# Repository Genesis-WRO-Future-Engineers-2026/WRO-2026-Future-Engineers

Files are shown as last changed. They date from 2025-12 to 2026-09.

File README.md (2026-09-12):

# Team Génesis
<p align="center">

    <br>
    <i>Logo del Equipo</i>
</p>

<p align="center">
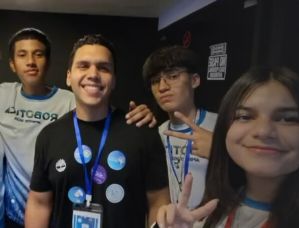
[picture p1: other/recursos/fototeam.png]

    <br>
    <i>Foto del Equipo</i>
</p>

# WRO - Future Engineers - Documentación del proyecto de robótica

## 👥Miembros del equipo
- **Johelis Acosta**
 *Rol*: Electrónica y mecánica
- **Miguel Mejías**
 *Rol*: Programador
- **Guillermo Fernández**
 *Rol*: Programador y diseñador

## 🧑🏻‍🔧Entrenador
- **Oswal Melean**
  *Ingeniero mecánico*

---

Bienvenidos a nuestro repositorio. Somos un grupo estudiantil dedicado a la robótica y la innovación, y en este espacio documentamos nuestro proceso de diseño: arquitectura de hardware, desarrollo de código, selección de componentes y el historial de pruebas de nuestro robot Eva01.

## 🔍Tabla de contenido

<!-- toc -->

- [1. 📚Descripción general](#1-descripción-general)
  - [1.1 Sobre el proyecto](#11-sobre-el-proyecto)
  - [1.2 Imagenes de Eva01](#12-imagenes-de-eva01)
  - [1.3 Video demostrativo](#13-video-demostrativo)
- [2. 🔩Movilidad y diseño mecánico](#2-movilidad-y-diseño-mecánico)
  - [2.1 Sistema de tracción](#21-sistema-de-tracción)
  - [2.2 Dirección](#22-direccion)
  - [2.3 Diseño del chasis](#23-diseño-del-chasis)
-  [3. 🔋Arquitectura de potencia y sensores](#3-arquitectura-de-potencia-y-sensores)
   - [3.1 Fuente de alimentación](#31-fuente-de-alimentación)
   - [3.2 Sensores y cámara](#32-sensores-y-cámara)
   - [3.3 Unidades de procesamiento](#33-unidades-de-procesamiento)
   - [3.4 Diagramas eléctricos](#34-diagramas-eléctricos)
   - [3.5 Consumo de energía](#35-consumo-de-energía)
- [4. 📐Arquitectura de software y estrategia para obstáculos](#4-arquitectura-de-software-y-estrategia-para-sortear-obstáculos)
  - [4.1 Reto abierto](#41-reto-abierto)
  - [4.2 Reto de obstáculos](#42-reto-de-obstáculos)
  - [4.3 Estacionamiento en paralelo](#43-estacionamiento-en-paralelo)
- [5. ⚙Pensamiento sistémico y decisiones de ingeniería](#5-pensamiento-sistémico-y-decisiones-de-ingeniería)
  - [5.1 Lenguajes de programación](#51-lenguajes-de-programación)
  - [5.2 Estructura del código](#52-estructura-del-código)
  - [5.3 Instrucciones de compilación](#53-instrucciones-de-compilación)
- [6. 📝Lista de componentes](#6-lista-de-componentes)
- [7. 💎Archivos de modelos 3D](#7-archivos-de-modelos-3d)
  - [7.1 Archivos STL originales](#71-archivos-stl-originales)
  - [7.2 Archivos modificados Eva01](#72-archivos-modificados-eva01)
- [8. 🛠️Instrucciones de montaje](#8-instrucciones-de-montaje)

    <!-- tocstop -->

## 1. 📚Descripción general

### 1.1 Sobre el proyecto

Este proyecto se centra en el diseño, la construcción y la programación de un vehículo autónomo capaz de superar con precisión y rapidez los retos y obstáculos de la competición «WRO Future Engineers».

Para el equipo Genesis, este reto representa la oportunidad perfecta para poner en práctica la teoría, combinando la pasión por la innovación tecnológica con la resolución creativa de problemas a través de un proceso sistemático de investigación, creación de prototipos e iteración constante.

La estructura de nuestro robot **Eva01** se basa en una arquitectura robusta inspirada en el hardware *zcar* (https://github.com/alexyu132/zcar). Hemos sometido este diseño a un exhaustivo proceso de reingeniería utilizando Fusion 360 y Blender para optimizar las dimensiones de los alojamientos de tornillos y tuercas, así como para personalizar las piezas y lograr un ajuste perfecto de nuestros componentes.

El núcleo del sistema está controlado por una Raspberry Pi 3 B+, que gestiona la lógica principal, con el apoyo de un módulo ESP32 S2 Mini para controlar los sensores y actuadores. Para lograr una navegación precisa y una evitación eficiente de obstáculos, el robot integra sensores de tiempo de vuelo VL53L0X (ToF) junto con un giroscopio MPU-6050 para la estabilización y la orientación de la trayectoria.

Todo este proceso de desarrollo ha estado respaldado por una documentación detallada que no solo optimiza nuestro flujo de trabajo, sino que también demuestra nuestras habilidades técnicas y de colaboración, así como nuestro compromiso con el aprendizaje práctico.

---

### 1.2 Imagenes de Eva01

<table>
  <tr>
    <td align="center">
      <b>Vista frontal</b><br>
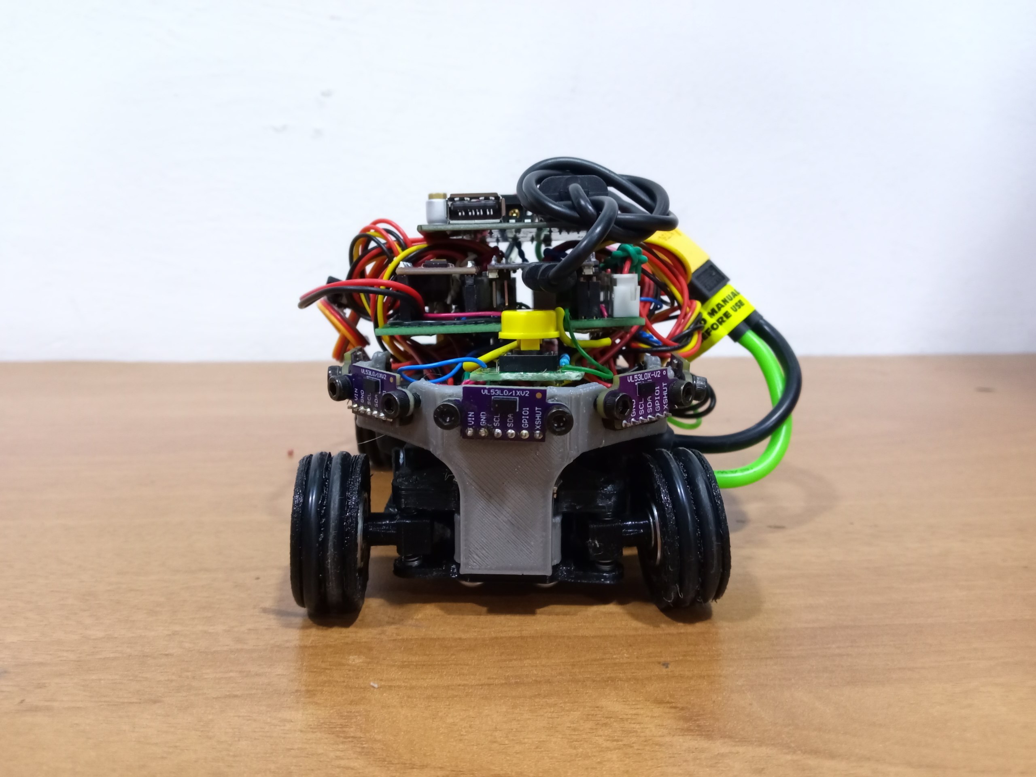
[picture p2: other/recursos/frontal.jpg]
      
    </td>
    <td align="center">
      <b>Vista trasera</b><br>
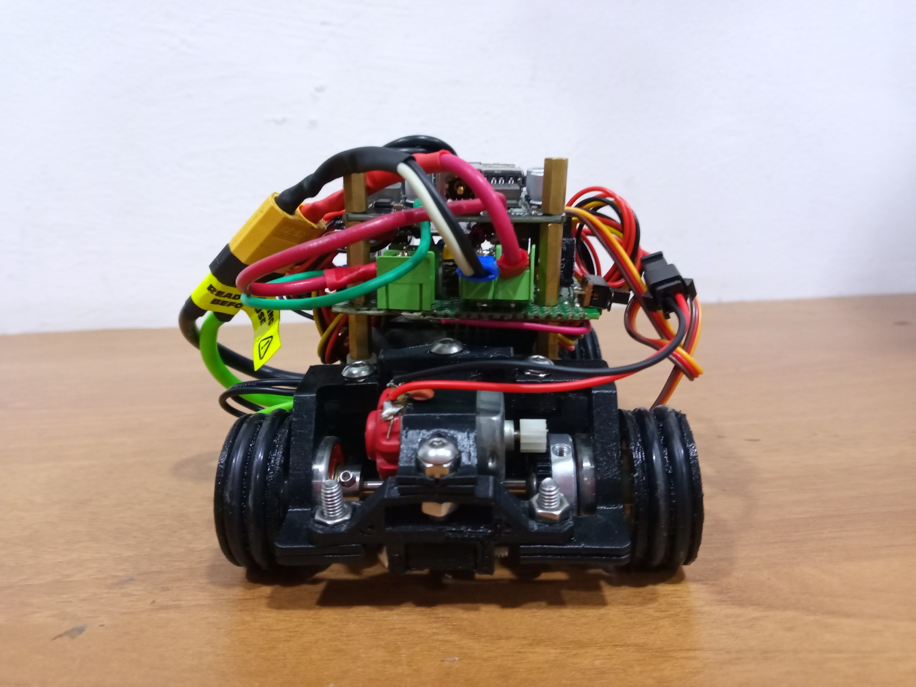
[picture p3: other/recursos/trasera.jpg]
      
    </td>
    <td align="center">
      <b>Vista lateral izquierda</b><br>
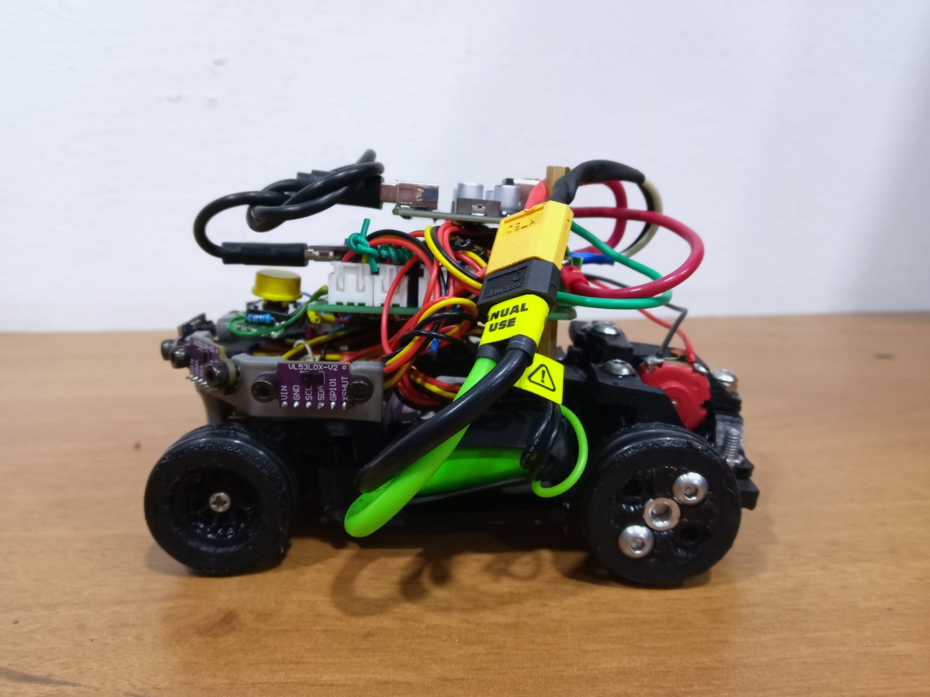
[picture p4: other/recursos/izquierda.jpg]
      
    </td>
  </tr>
  <tr>
    <td align="center">
      <b>Vista lateral derecha</b><br>
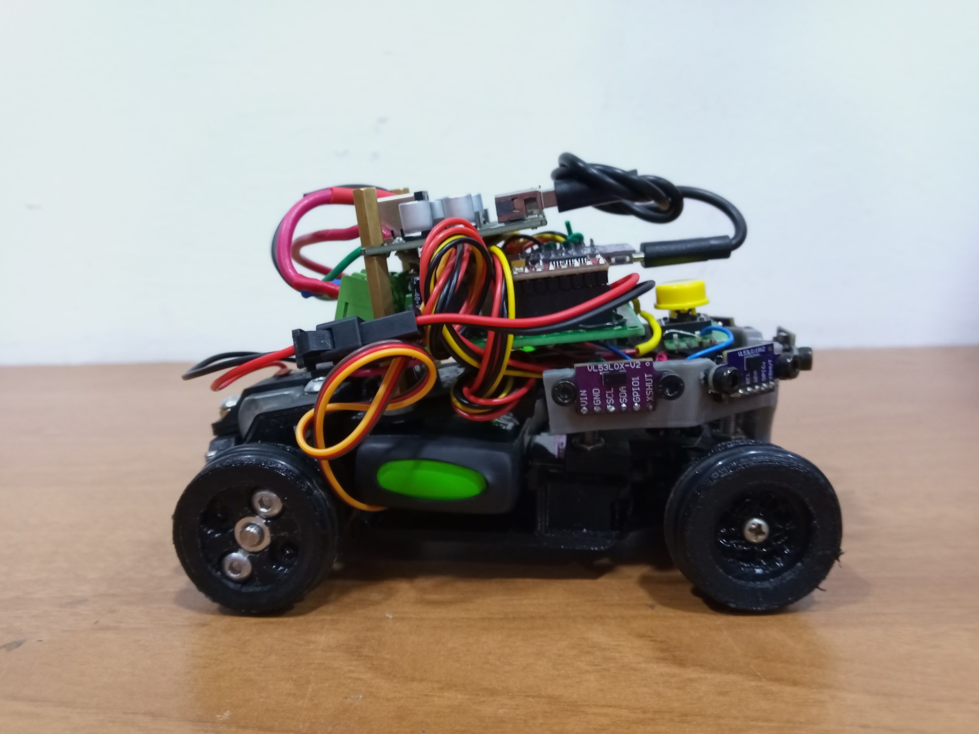
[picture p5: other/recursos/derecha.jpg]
      
    </td>
  <td align="center">
  <b>Vista desde arriba</b><br>
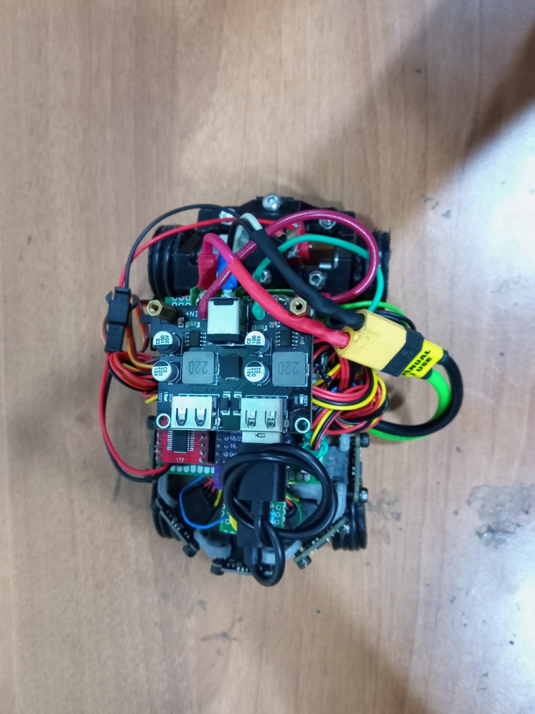
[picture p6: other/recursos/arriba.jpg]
  
</td>
    <td align="center">
      <b>Vista desde abajo</b><br>
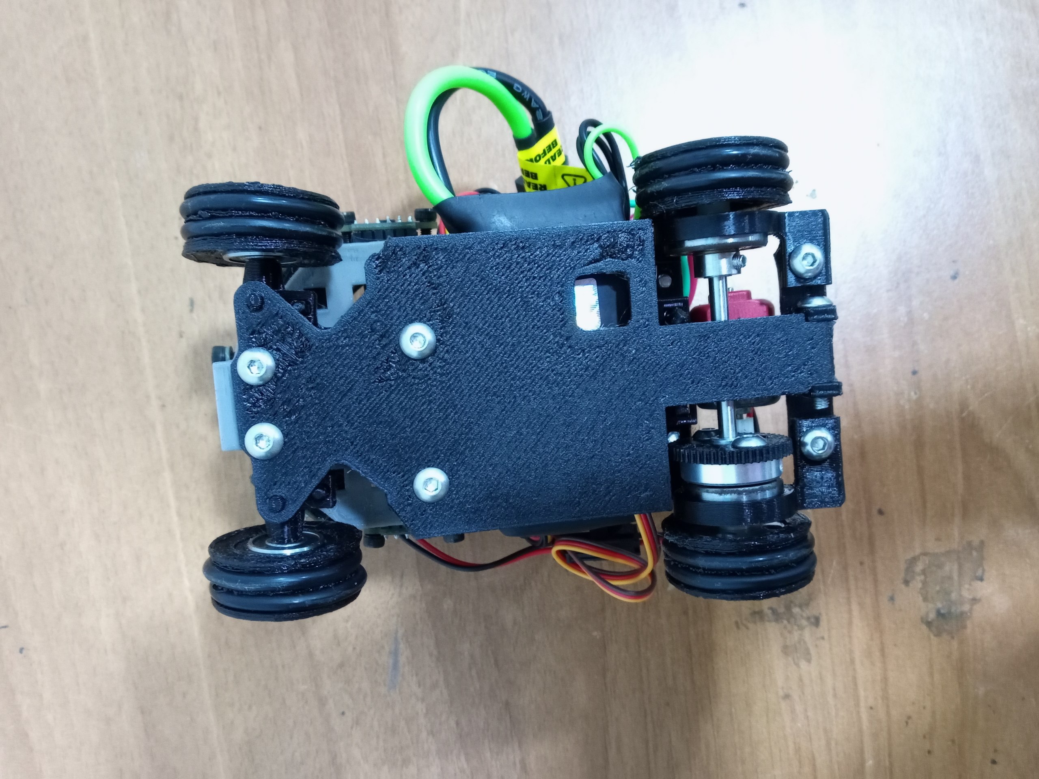
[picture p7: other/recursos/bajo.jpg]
      
    </td>
  </tr>
</table>

---

### 1.3 Video demostrativo

Parte 1: Vídeo del reto sin obstáculos (https://youtu.be/Bd5FpVkRgWs)

[Parte 2: Vídeo del reto de obstáculos]()

<p align="right">
  <a href="#top">Back To Top</a>
</p>

---

## 2. 🔩Movilidad y diseño mecánico

- **Sistema de tracción:** tracción diferencial en 2 ruedas (ruedas traseras).
- **Dirección:** dirección en las ruedas delanteras mediante el servomotor MG90S.

### 2.1 Sistema de tracción

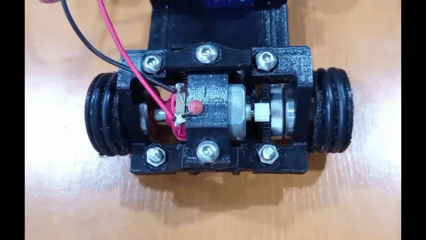
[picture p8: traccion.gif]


**Motor: Micro motor dc 130**

<table>
  <tr>
    <td align="center" width="300" >
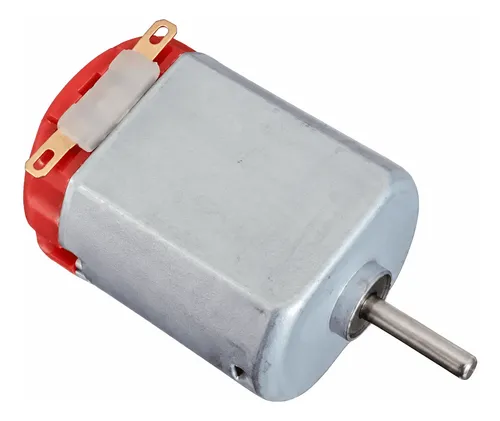
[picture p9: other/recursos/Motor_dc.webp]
   
    </td>
    <td>
      <h3>Especificaciones:</h3>
      <ul>
          <li><b>Voltaje:3 V – 6 V</li>
          <li><b>Velocidad sin carga:12500 – 15000 RPM (a 6V)</li>
          <li><b>Stall torque:0,15 – 0,20 kg-cm</li>
          <li><b>Corriente sin carga:0,07 A – 0,15 A</li>
          <li><b>Relación de transmisión:1:1 (sin reductora)</li>
      </ul>
    </td>
  </tr>
</table>

**Motivo de la selección:**

- **Diseño compacto y liviano:** Permite optimizar al máximo el peso del chasis, manteniendo el centro de gravedad bajo y reduciendo la demanda sobre la batería durante las rondas de competencia.

- **Respuesta y aceleración rápida:** Presenta una baja inercia mecánica, facilitando aceleraciones inmediatas y cambios de velocidad.

- **Fácil integración:** Es una alternativa sumamente accesible, fácil de montar y rápida de reemplazar si se requiere mantenimiento durante las pruebas.

**Sistema de Tracción y Trabajo Futuro:**

El motor acciona las ruedas traseras a través de un eje metálico continuo de transmisión directa. Esta configuración garantiza que ambas ruedas reciban el mismo par y mantengan una velocidad sincronizada al 100%, eliminando descompensaciones en el avance en línea recta y evitando pérdidas por fricción de mecanismos complejos.

Aunque el eje rígido requiere compensar el radio de giro a través de la dirección delantera con el servomotor MG90S, la navegación actual depende completamente del control por sensores externos (VL53L0X y MPU6050). Si bien esta solución es económica y funcional para la etapa actual del prototipo, la falta de retroalimentación interna limita la precisión en el control de la distancia recorrida. Por ello, nuestra visión a futuro es reemplazar este por un motor con encoder integrado, lo que simplificará la programación y nos permitirá implementar un control mucho más preciso en pista.

**Montaje:**

Se instala mediante una abrazadera de motor impresa en 3D atornilladas al chasis. Esto permitirá futuras modificaciones para el mejoramiento de la tracción. 

[Abrazadera del motor](<models/Stls/Soporte motor.stl>)

- Cables del motor conectados directamente al puente h TB6612FNG.
- Ruedas conectadas a su tren de rodaje impreso en 3D con filamento PETG.

---

### 2.2 Dirección

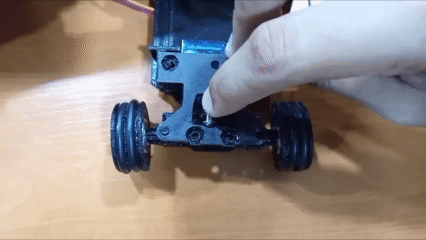
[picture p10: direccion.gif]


#### Servomotor: MG90S

<table>
  <tr>
    <td align="center" width="300" >
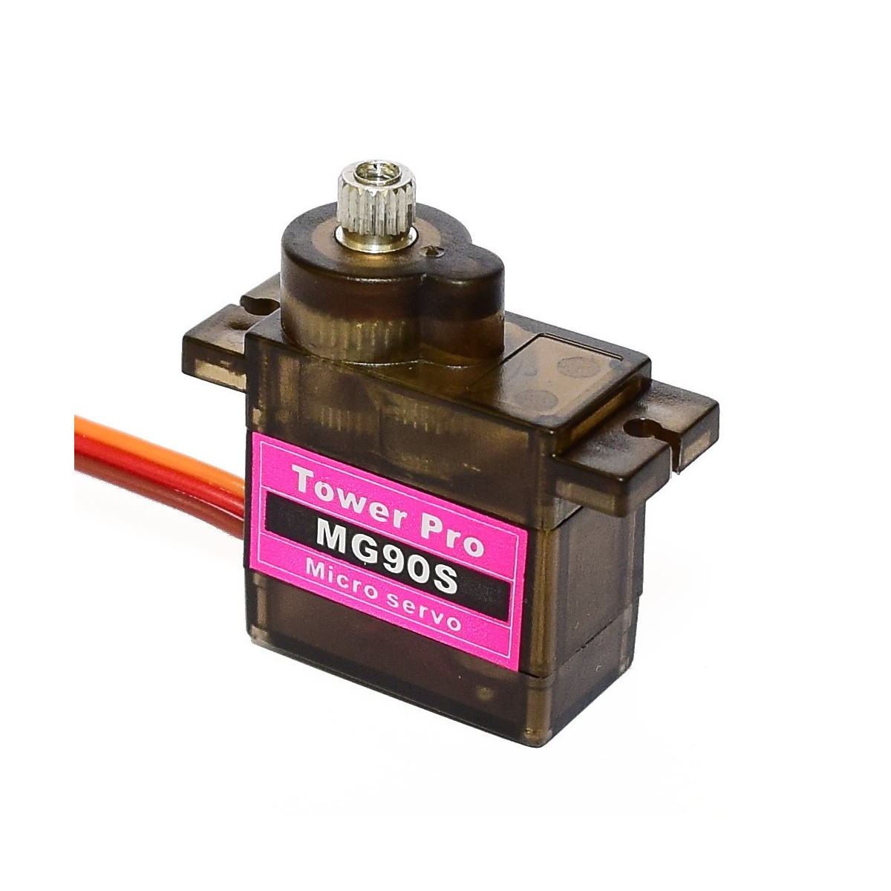
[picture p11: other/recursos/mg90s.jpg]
   
    </td>
    <td>
      <h3>Especificaciones:</h3>
      <ul>
          <li><b>Voltaje:4,8 V – 6,0 V</li>
          <li><b>Velocidad:0,08 – 0,10 s/60°</li>
          <li><b>Stall torque:1,8 – 2,2 kgf/cm</li>
          <li><b>Engranaje:Metal</li>
          <li><b>Tipo:Análogo / Digital</li>
      </ul>
    </td>
  </tr>
</table>

#### Motivo de la selección:

- Su pequeño tamaño y la interfaz PWM facilitan su control a través del ESP32-S2 Mini.

- Tiene el par de bloqueo (stall torque) suficiente para dirigir las ruedas delanteras con precisión.

- Ofrece un equilibrio entre velocidad y estabilidad durante los giros y los cambios de dirección.

- Este servomotor se utiliza ampliamente en la robótica, por lo que existe mucha documentación y kits de montaje disponibles.

Tomando como base el diseño modificado del hardware "zcar", adaptamos su dirección Ackermann para optimizar el paso por curva. Este sistema evita que los neumáticos deslicen al hacer que la rueda interior de la curva gire con un ángulo más pronunciado que la exterior.

El mecanismo funciona mediante un servomotor que desplaza un pin central a través de una ranura, empujando los brazos articulados de las ruedas. La clave radica en la inclinación del pin respecto a la barra de empuje: al mover el servo, se aplica una mayor diferencia angular a la rueda interna del giro. Así se logra un paso por curva fluido y preciso.

 *Imagen creada a partir de referencias de la web*
 
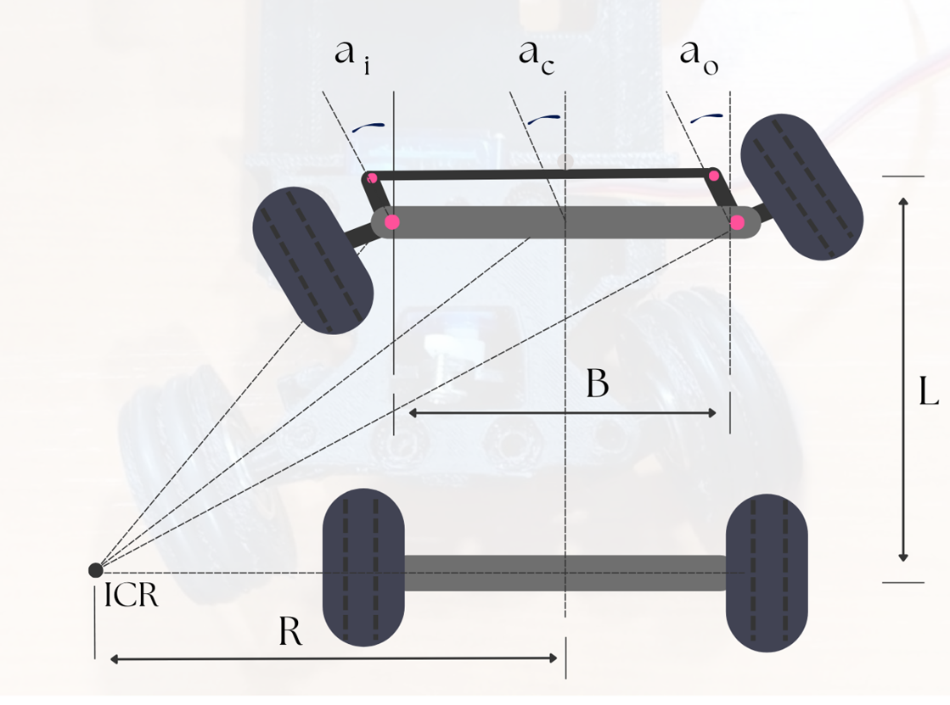
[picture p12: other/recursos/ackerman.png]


Describiremos a continuación el significado de cada término:

**ICR (Centro Instantáneo de Rotación):** Es el punto alrededor del cual el eje delantero está girando.

**R :** Es la radio del giro del vehículo, medida desde el ICR hasta el centro del eje trasero.

**L :** Es la distancia entre el eje delantero y el eje trasero de Eva01, o la distancia de nuestro eje transmisor.

**B :** Es la distancia entre los muñones de dirección (La pieza en la que va la rueda y se conecta a la dirección).

**a(i) :** Es el ángulo de giro de nuestra rueda interior respecto a la curva.

**a(o) :** Es el ángulo de nuestra rueda exterior respecto al giro.

Rediseñamos y mejoramos el mecanismo de dirección para satisfacer las demandas físicas y mecánicas del robot. Los aspectos clave de este desarrollo fueron:

- **Modelado en Autodesk Fusion 360:** Partimos del diseño base y utilizamos Fusion 360 para realizar las modificaciones geométricas necesarias en el sistema de dirección, adaptando componentes clave como la barra de la dirección y las dimensiones del muñón que sostiene las ruedas.

- **Prototipado rápido e iteración física:** Basamos nuestras pruebas en la fabricación directa de componentes. Imprimíamos en 3D las piezas modificadas en formato STL y evaluamos su desempeño en el chasis real; si un elemento no funcionaba según lo previsto (como requerir un mayor largo en la barra de dirección), ajustábamos el modelo 3D y volvíamos a imprimir.

- **Adaptación de rines y ruedas (Dirección vs. Tracción):** Para integrar de forma adecuada el eje metálico en el sistema de tracción trasera, adaptamos la geometría de los rines. Los rines delanteros (dirección) se diseñaron ligeramente más pequeños en diámetro interno, lo que hace que el perfil del neumático sea más grueso en esa zona; sin embargo, físicamente las ruedas delanteras y traseras mantienen exactamente el mismo tamaño externo para conservar el equilibrio y la altura del chasis.

- **Fabricación en PETG:** Todas las piezas adaptadas e impresas fueron fabricadas utilizando filamento PETG (a excepción de los neumáticos impresas en TPU), garantizando mayor resistencia mecánica, tenacidad ante impactos y durabilidad en las uniones y puntos de estrés térmico o mecánico.

#### Calibración e implementación

Para asegurarnos de que la dirección funcionara correctamente en ambas direcciones, llevamos a cabo un proceso de calibración práctico e iterativo:

- **Ajuste dimensional:** Modificamos de forma iterativa el modelo digital (ajustando la barra de dirección y el muñón) y probamos el encaje físico de las piezas impresas.

- **Verificación mecánica:** Tras cada impresión y montaje, evaluamos el comportamiento dinámico del servo y el varillaje, comprobando que las ruedas giraran de forma simétrica, sin fricción excesiva ni holguras en el muñón.

- **Consolidación del diseño:** Una vez alcanzado el ángulo de giro óptimo, fijamos las dimensiones definitivas en el modelo final.

#### Montaje:

Todo el mecanismo de dirección mejorado se ensambló de manera robusta utilizando un sistema de uniones impresas con filamento con tornillos y tuercas M3, sujetando firmemente el servo, los muñones y las barras de dirección a la estructura principal del chasis.

### 2.3 Diseño del chasis

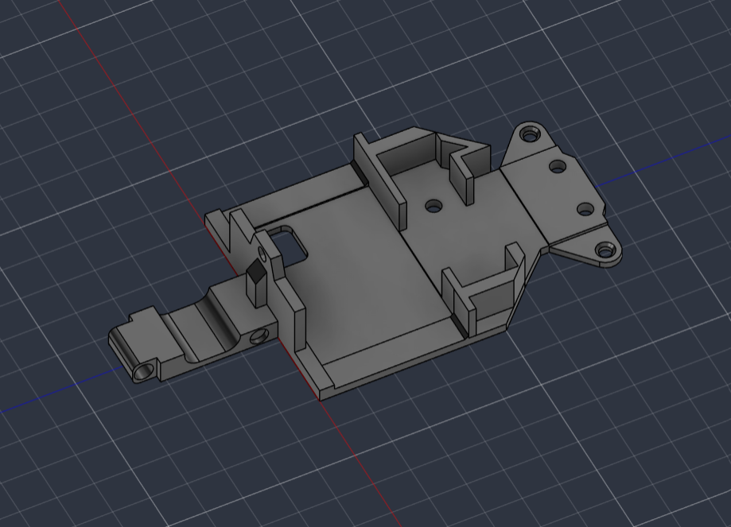
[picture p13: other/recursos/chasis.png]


|**Dimensiones**|**Valor**|
|---|---|
| Largo | 126 mm  |
| Ancho | 62 mm |
| Alto máx | 25.3 mm |
| Alto min | 2.5 mm  |

#### Diseño y Estructura del Chasis

El chasis principal de nuestro vehículo toma como base un diseño de código abierto, el cual fue adaptado y optimizado mediante Autodesk Fusion 360 para ajustarse a nuestro sistema de tracción y geometría de dirección. Para garantizar la modularidad y facilitar el mantenimiento, la transmisión trasera y el mecanismo de dirección delantero con su servomotor se montan en placas desmontables impresas en 3D. Estas placas permitieron realizar ajustes finos durante la fase de pruebas hasta alcanzar una alineación precisa con el resto del tren motriz.

La distribución interna coloca los componentes de mayor peso en los extremos (motor y servo), reservando la zona central para la electrónica. Allí, una placa de circuito a medida simplifica el cableado y optimiza el espacio. El diseño se complementa con piezas independientes imprimibles, como abrazaderas para el motor y soportes dedicados para los sensores, lo que facilita el reemplazo o ajuste individual de cada elemento.

Todo el conjunto estructural fue impreso en filamento PETG, seleccionado por su mayor resistencia mecánica, durabilidad frente a impactos y tolerancia térmica en comparación con el PLA convencional.

<p align="right">
  <a href="#top">Back To Top</a>
</p>

---

## 3. 🔋Arquitectura de potencia y sensores

### 3.1 Fuente de alimentación

#### Batería high performance

<table>
  <tr>
    <td align="center" width="300" >
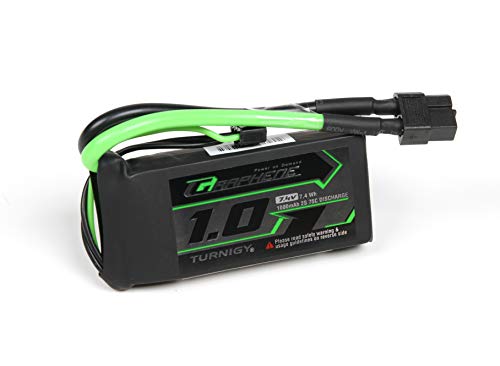
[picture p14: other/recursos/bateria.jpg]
   
    </td>
    <td>
      <h3>Específicacones:</h3>
      <ul>
          <li>Modelo: Turnigy Graphene Panther</li>
          <li>Voltaje nominal: 7.4 V 2S</li>
          <li>Voltaje Máximo: 8.4 V (4.2 V por celda)</li>
          <li>Voltaje de Corte Seguro: 6.4 V - 6.6 V (3.2 V - 3.3 V por celda)</li>
          <li>Capacidad: 1000 mAh (1.0 Ah)</li>
          <li>Tasa de Descarga: 75C constante</li>
          <li>Tiempo de carga: 1.25 Horas</li>
      </ul>
    </td>
  </tr>
</table>

Para el Eva 01, diseñamos un sistema de distribución de energía centralizado a partir de una única batería, priorizando la estabilidad de la lógica de control frente al consumo de los motores.

Seleccionamos esta batería principalmente por su alta capacidad de entrega de corriente constante. Al trabajar con motores con tracción y un servomotor de dirección que se activan de forma simultánea, el sistema demanda picos de corriente muy elevados. La tecnología de esta batería nos garantiza que el flujo de energía sea masivo y constante, evitando caídas de tensión bruscas que podrían reiniciar o desestabilizar la Raspberry Pi 3 b+ o la ESP32-S2. Además, su excelente relación peso-potencia nos permite mantener el chasis ligero sin sacrificar la autonomía.

Para evitar que el ruido inductivo de los motores interfiriera con los procesadores, decidimos dividir la alimentación en tres ramificaciones independientes:

```text
                  ┌──► [Conversor Step-Down USB 5V] ──────► Raspberry Pi 3 B+ (Procesamiento)
                  │
[Batería LiPo 2S]─┼──► [Regulador Lineal LM7805] ────────► Servomotor (Dirección)
                  │
                  ├──► [Puente H TB6612FNG (Paralelo)] ──► Motor DC 6V (Tracción)
                  │         └─► [ESP32-S2] (Lógica)
                  │
                  └──► [Divisor de Tensión] ────────────► Pin 14 ESP32-S2 (Monitoreo)
```

- **Alimentación de la Raspberry Pi 3 B+**
Utiliza un **conversor regulador (Step-Down) doble USB** conectado directo a la batería, garantizando el suministro estable de 5V y el amperaje continuo que requiere la Pi para procesar datos sin caídas de voltaje.

- **Incremento de Torque (Puente H en Paralelo)**
Para maximizar la fuerza del motor de tracción de 6V, **conectamos en paralelo ambos canales del puente H TB6612FNG** (puenteando señales de control y salidas de potencia). Esto duplica la capacidad de corriente, evitando sobrecalentamientos ante altas exigencias mecánicas. La ESP32-S2 toma su alimentación lógica de esta etapa.

- **Aislamiento del Servomotor de Dirección**
Alimentamos el servomotor de forma exclusiva con un regulador lineal **LM7805** para aislar por completo el ruido que generan sus movimientos rápidos, protegiendo la estabilidad de los microcontroladores.

- **Monitoreo y Protección de la Batería**
Implementamos un **divisor de tensión** conectado a un pin 14 de la ESP32-S2 para medir el voltaje de la batería de forma segura. Si el nivel de carga desciende de su límite crítico, el sistema activa un **LED de advertencia** para evitar la degradación de las celdas.

#### Conversor regulador (Step-Down) doble USB

<table>
  <tr>
    <td align="center" width="300" >
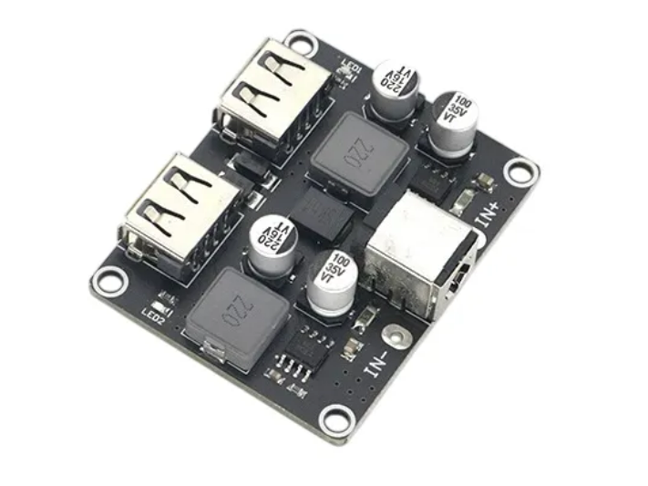
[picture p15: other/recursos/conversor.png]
   
    </td>
    <td>
      <h3>Especificaciones:</h3>
      <ul>
          <li><b>Rango de voltaje de entrada:6 V – 32 V DC</li>
          <li><b>Voltaje de salida:5 V por defecto (3 V – 12 V en carga rápida)</li>
          <li><b>Potencia de salida máxima:24 W por puerto (ej. 5V/3.4A, 9V/2.5A, 12V/2A)</li>
          <li><b>Eficiencia de conversión:90% – 97%</li>
      </ul>
    </td>
  </tr>
</table>

#### Controlador del motor: TB6612FNG

<table>
  <tr>
    <td align="center" width="300" >
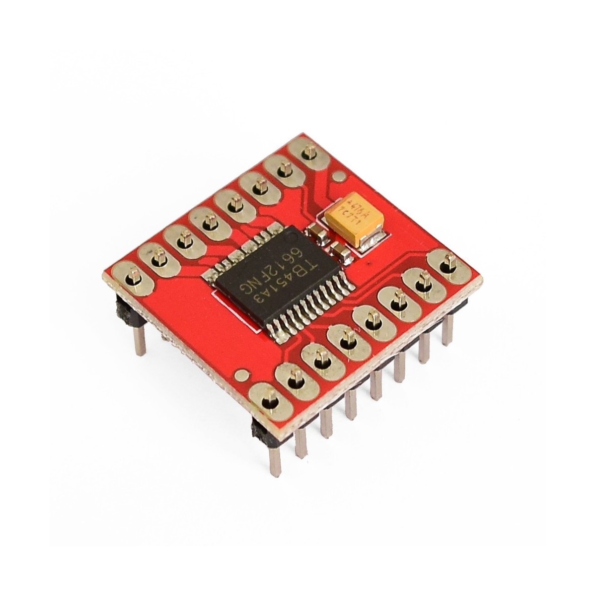
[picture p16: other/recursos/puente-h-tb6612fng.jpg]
   
    </td>
    <td>
      <h3>Especificaciones:</h3>
      <ul>
          <li><b>Rango de voltaje de motores (VM): 4.5 V – 13.5 V</li>
          <li><b>Voltaje de lógica (VCC): 2.7 V – 5.5 V</li>
          <li><b>Corriente de salida continua: 1.2 A por canal (2.4 A en paralelo)</li>
          <li><b>Corriente pico máxima: 3.2 A por canal</li>
          <li><b>Resistencia típica R<sub>DS(on)</sub> (alta + baja):</b> 0.5 Ω</li>
          <li><b>Frecuencia máxima de PWM: Hasta 100 kHz</li>
      </ul>
    </td>
  </tr>
</table>

#### Regulador lineal: LM7805

<table>
  <tr>
    <td align="center" width="300" >
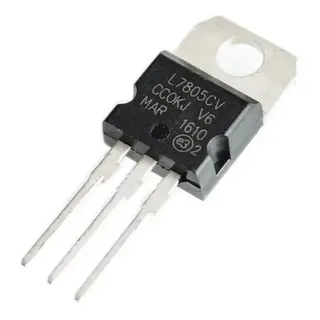
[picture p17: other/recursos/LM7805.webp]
   
    </td>
    <td>
      <h3>Especificaciones:</h3>
      <ul>
          <li><b>Voltaje de salida:5 V DC (fijo)</li>
          <li><b>Rango de voltaje de entrada:7 V – 25 V</li>
          <li><b>Corriente de salida máxima:1.5 A</li>
      </ul>
    </td>
  </tr>
</table>

---

### 3.2 Sensores y cámara

#### Sensor tiempo de vuelo VL53L0X

El VL53L0X es un sensor de distancia pequeño y muy utilizado que emplea la tecnología de tiempo de vuelo (ToF) para medir la distancia a un objeto mediante la emisión de un pulso de luz láser infrarroja invisible y el cálculo del tiempo que tarda en regresar.

Lo hemos elegido para este proyecto debido a tres ventajas clave:

-  **Tamaño ultracompacto**: su reducido tamaño permite integrarlo fácilmente en espacios reducidos sin comprometer el diseño del prototipo.
  
-  **Fácil integración**: ofrece una excelente compatibilidad y bibliotecas listas para usar, lo que simplifica enormemente la programación.
  
-  **Alta velocidad**: es capaz de realizar mediciones de distancia por láser en un tiempo récord, lo que garantiza lecturas rápidas, precisas y en tiempo real.

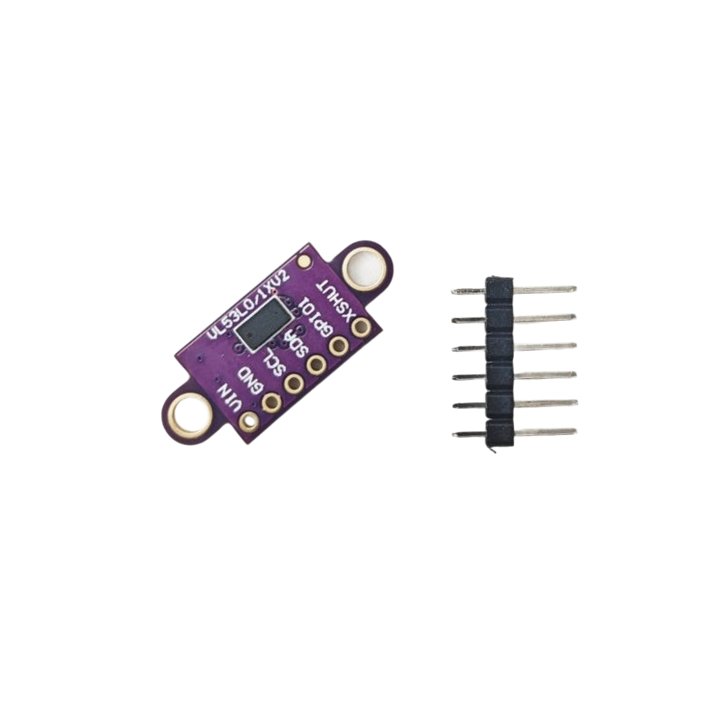
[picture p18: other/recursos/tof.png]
  

|**Dimensiones**|**Valor**|
|---|---|
| Largo | 25 mm |
| Alto | 1 mm |
| Ancho | 10,7 mm |
| Peso | 0,8 g |

 **Observaciones**

 Al trabajar con la tecnología Time-of-Flight (ToF) mediante un láser VCSEL infrarrojo invisible, el sensor emite un haz de luz y necesita que los fotones reboten en la superficie y regresen directamente al receptor SPAD integrado. Debido a esto, el dispositivo es sensible a las inclinaciones, por lo que requiere una alineación perpendicular (a 90°) frente a las paredes u obstáculos para garantizar lecturas precisas.

Asimismo, es importante ubicarlo a una altura de 4 cm a 5 cm del suelo (en el Eva01 lo colocamos a 5 cm) para optimizar el rango de detección y evitar fluctuaciones no deseadas con el piso.

El Eva01 utiliza 5 de estos sensores VL53L0X dispuestos a 45° entre sí. Al mantener esta separación angular y contar con un campo de visión (FoV) de 25°, los haces de luz no se solapan, lo que elimina el riesgo de interferencias cruzadas entre lecturas adyacentes.

#### Sensor de unidad de medición inercial (IMU MPU-6050)

El MPU-6050 es una unidad de medición inercial (IMU) muy utilizada que integra un giroscopio de 3 ejes y un acelerómetro de 3 ejes en un único chip. Utiliza esta combinación para medir con precisión la aceleración lineal y la velocidad angular, lo que permite determinar la orientación, la inclinación y el movimiento del prototipo en el espacio.

Ventajas del dispositivo:

- **Tamaño ultracompacto**: al integrar el acelerómetro y el giroscopio en una placa minúscula, maximiza la eficiencia del espacio dentro de nuestro circuito.
  
- **Fácil integración**: gracias a la comunicación mediante el protocolo I2C y a una amplia gama de bibliotecas disponibles, la configuración y la lectura de datos son extremadamente sencillas.
  
- **Alta velocidad**: cuenta con un procesador de movimiento digital (DMP) interno que ejecuta rápidamente algoritmos complejos, proporcionando datos estables en tiempo real sin sobrecargar el microcontrolador principal.

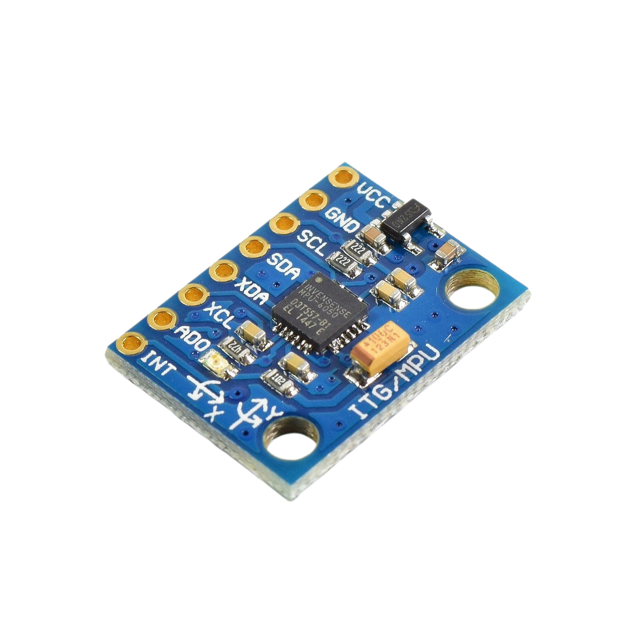
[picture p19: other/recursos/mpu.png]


|**Dimensiones**|**Valor**|
|---|---|
| Largo | 21.2 mm |
| Ancho | 16.4 mm |
| Alto | 3.3 mm  |
| Peso | 2.1 g |

#### Cámara de visión artificial (cámara web FHD de 1080p modificada)

Para equipar el vehículo con un sistema de visión artificial, integramos una cámara web de alta definición (FHD de 1080p). Sin embargo, dado que la unidad comercial original (incluidas su carcasa y su soporte) era demasiado grande y pesada (80 mm x 33 mm x 40 mm), llevamos a cabo una modificación del hardware eliminando toda la estructura plástica externa. Esto nos permitió extraer el módulo interno de la cámara, lo que dio como resultado una placa de circuito funcional que mide tan solo **25 mm x 28,5 mm**.

Ventajas clave del dispositivo modificado:

- **Tamaño ultracompacto (tras la modificación)**: al reducir drásticamente sus dimensiones a tan solo 25 mm x 28,5 mm, pudimos montarlo en la parte delantera del vehículo sin comprometer la aerodinámica ni el diseño del chasis.
  
- **Fácil integración y estabilidad**: A pesar de estar desmontado, conserva la conectividad USB nativa y la compatibilidad directa con algoritmos de visión por ordenador (como OpenCV), lo que simplifica la programación.
  
- **Alta velocidad y resolución**: Mantiene la captura en 1080p FHD, procesando imágenes nítidas en tiempo real, un factor crítico para la toma de decisiones mientras el vehículo está en movimiento.

#### Comparación de dimensiones (cámara web)

<div align="left">
 <i>Antes</i>
 <br>
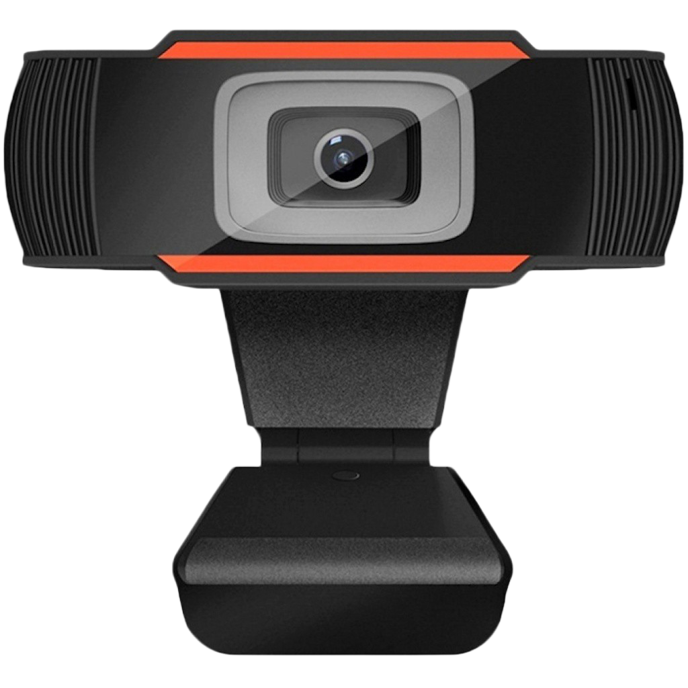
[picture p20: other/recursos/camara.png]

</div> 

| **Estado** |**Largo** |**Ancho**|**Alto**|
|---|---|---|---|
| Con carcasa (original) | 80 mm | 40 mm | 33 mm  |

<div align="left">
 <i>Después</i>
 <br>
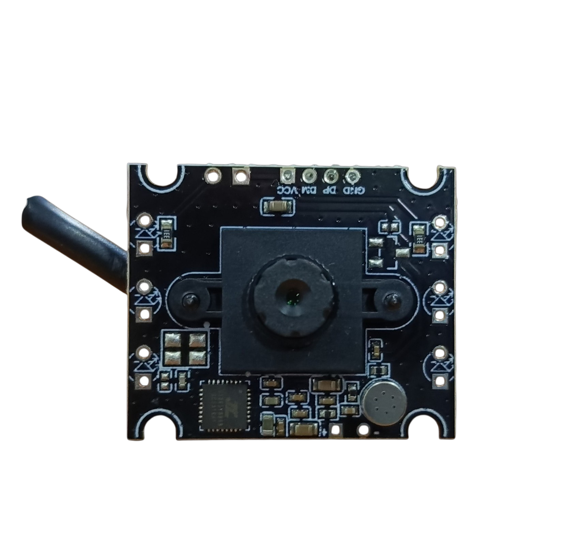
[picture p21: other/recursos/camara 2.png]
 
</div>

| **Estado** |**Largo** |**Ancho**|**Alto**|
|---|---|---|---|
| Sin carcasa (modificado) | 25 mm | 28,5 mm | 2 mm |

---

### 3.3 Unidades de procesamiento 

#### Raspberry Pi 3 b+

Equipada con un procesador ARM Cortex-A53 de 64 bits y 1,4 GHz, **la Raspberry Pi 3 B+** es nuestro controlador principal. Decidimos utilizar la Raspberry Pi 3 B+ por varias razones, entre ellas:

- **Compatibilidad**: hay muchos componentes (como las cámaras web USB estándar) que son fáciles de integrar con la Raspberry Pi 3 B+.
  
- **Potencia**: la Raspberry Pi 3 B+ ofrece un rendimiento eficiente y equilibrado; gracias a ello, el dispositivo gestiona con facilidad tareas exigentes, como el procesamiento de imágenes en tiempo real.
  
- **Portabilidad**: La Raspberry Pi 3 B+ destaca entre los controladores; con un peso de tan solo 45 g, es ligera, lo que la convierte en una opción práctica y fiable para su integración en el Eva 01.

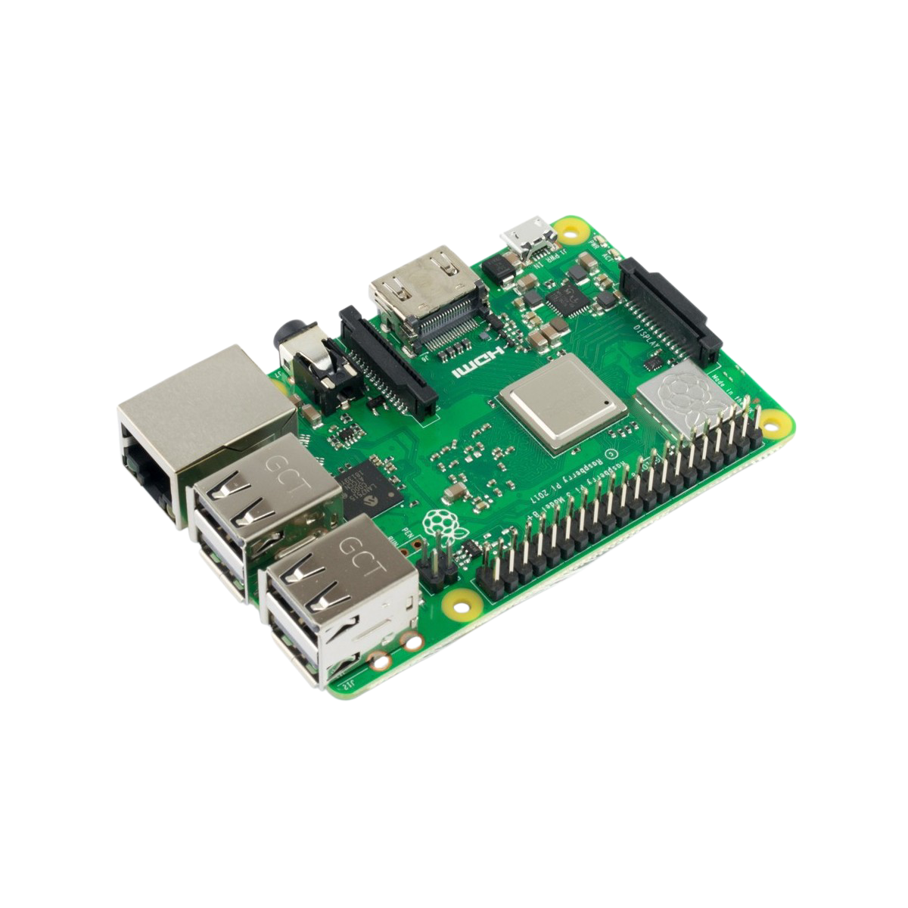
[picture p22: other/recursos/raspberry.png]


|**Dimensión**|**Valor**|
|---|---|
| Longitud | 85 mm |
| Altura | 17 mm |
| Anchura | 56 mm |
| Peso | 45 g |

#### Esp32-S2 Wemos Mini

Aunque la Raspberry Pi 3 B+ es capaz de procesar imágenes en tiempo real, nos dimos cuenta de que necesitaba algo de ayuda para evitar que se sobrecargara de información; por ello, decidimos incorporar un **ESP32-S2 Mini** para controlar los sensores y sus actuadores con el fin de alcanzar el nivel de procesamiento necesario. Asimismo, aprovechamos la conectividad Wi-Fi integrada de este microcontrolador para transmitir y visualizar en tiempo real (únicamente  durante las prácticas) las lecturas de los sensores a través de una app realizada en Firebase.

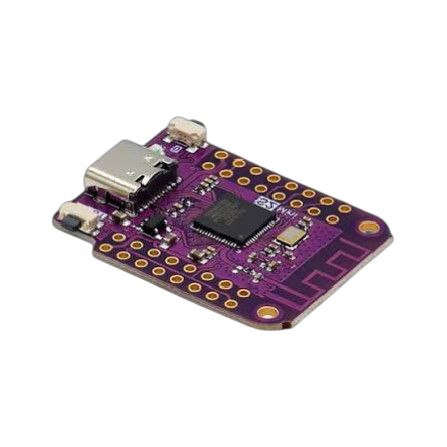
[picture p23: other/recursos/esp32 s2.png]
 

|**Dimensión**|**Valor**|
|---|---|
| Longitud | 34.3 mm |
| Altura | 25.4 mm |
| Anchura | 25.4 mm |
| Peso | 5.3 g |

### 3.4 Diagramas eléctricos

**Diagrama de Bloques del Sistema**
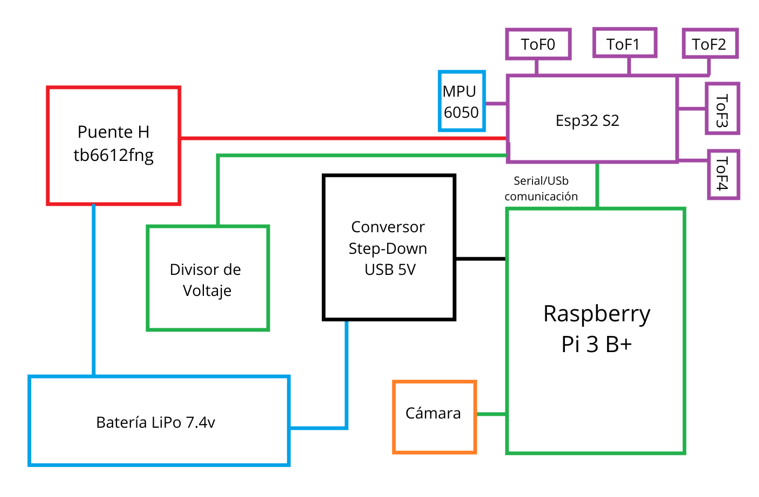
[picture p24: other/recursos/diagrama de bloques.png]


---

**Diagrama sensores:**
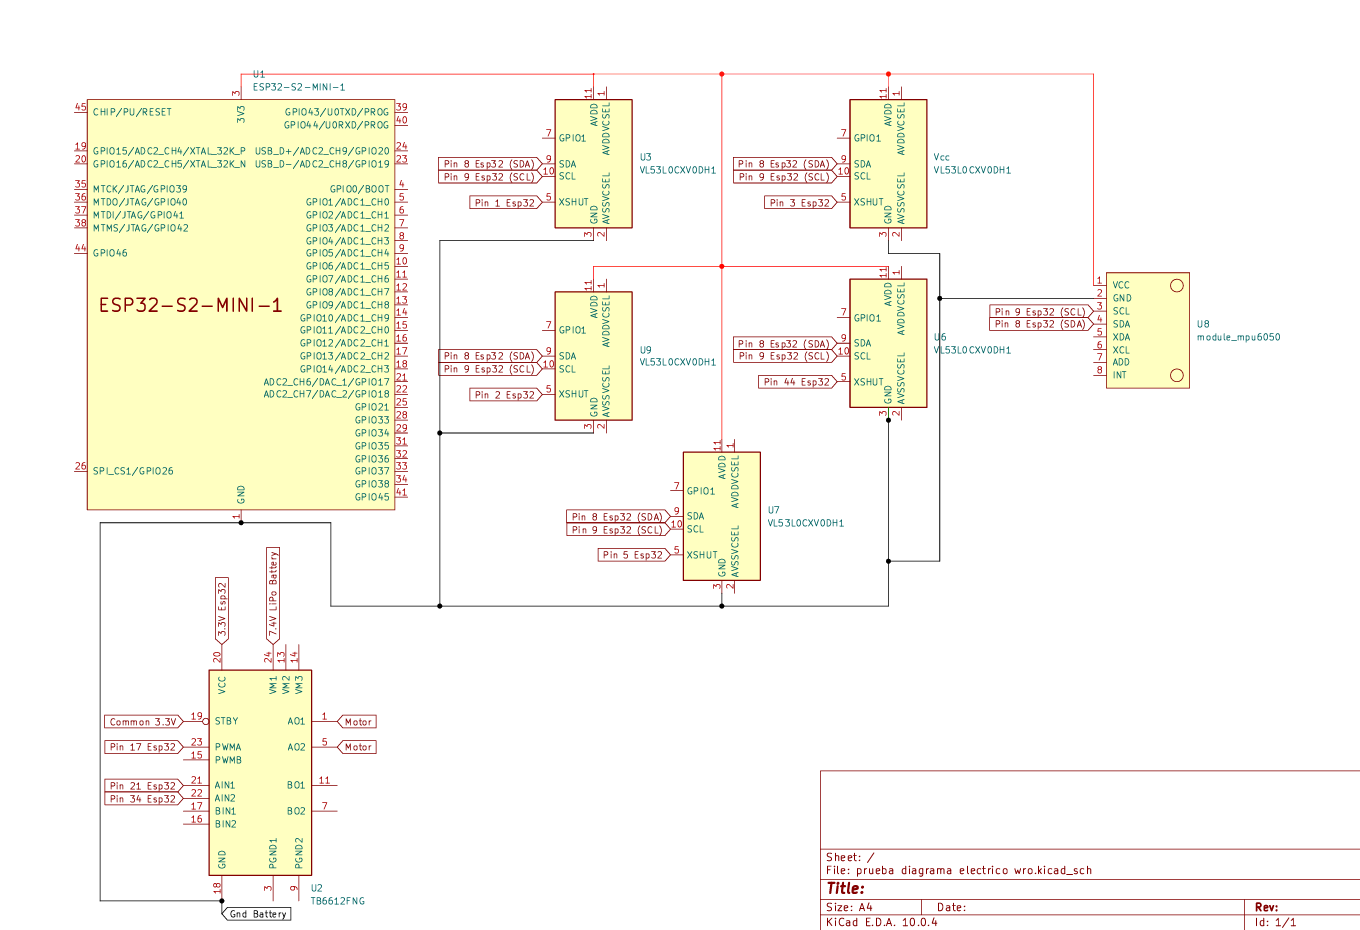
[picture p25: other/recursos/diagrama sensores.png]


---

**Diagrama motores:**
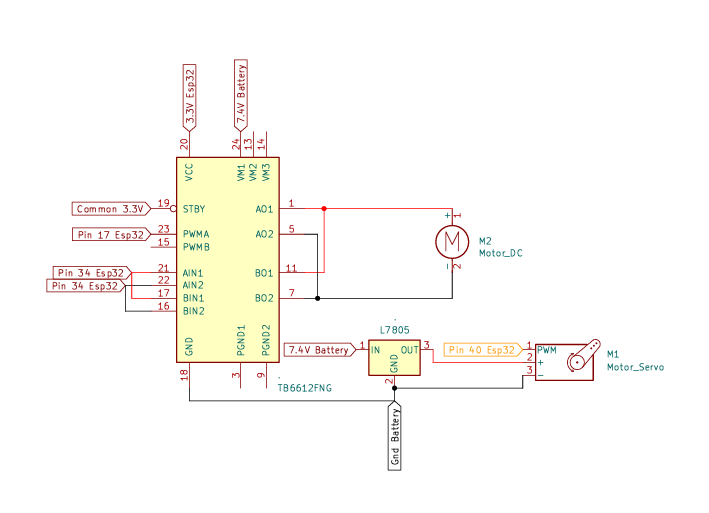
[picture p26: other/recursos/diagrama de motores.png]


---

**Diagrama divisor de voltaje:**
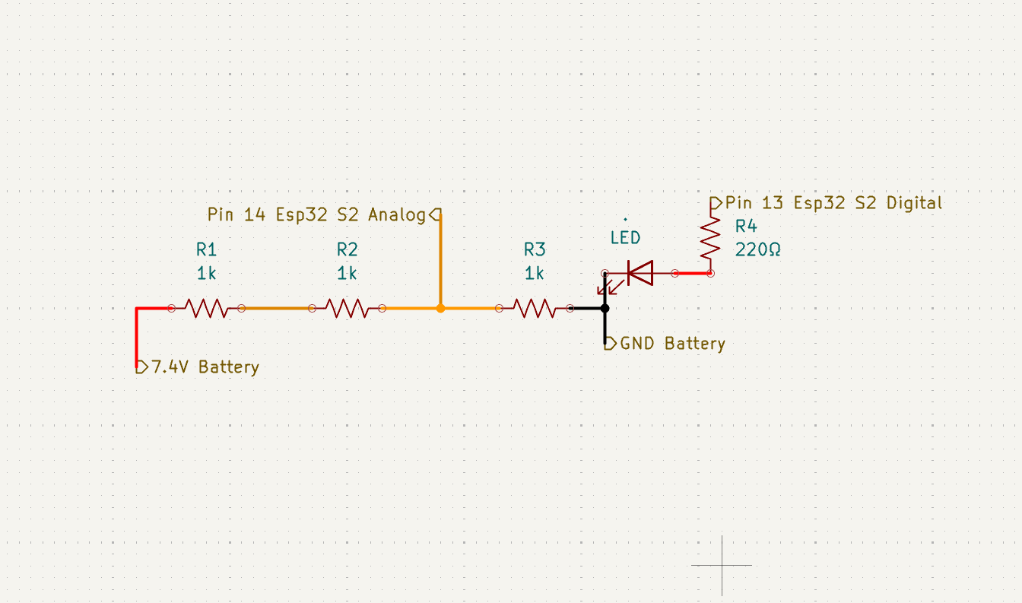
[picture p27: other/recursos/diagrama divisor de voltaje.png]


Tuvimos que decidir cómo integrar todo el circuito. Si dejábamos los componentes separados y conectados solo con cables sueltos, el sistema ocupaba demasiado espacio y resultaba muy desordenado. Por ello, optamos por diseñar y ensamblar nuestra propia placa soldando todo sobre una perfboard. Esto nos permitió compactar considerablemente el circuito, mantener las conexiones ordenadas y fijas, y al mismo tiempo conservar la flexibilidad para corregir fallas o reemplazar componentes sin tener que rediseñar una PCB industrial. No obstante, nuestra visión a futuro es reemplazar esta perfboard por una PCB prefabricada que permita optimizar aún más el diseño y escalar la producción. [Toca aquí para ver el proceso](<Design process/perfboard process>)

---

### 3.5 Consumo de energía

| Componente | Alimentación (V)  | Corriente Típica | Corriente Pico | Potencia Típica (W) |
|---|---|---|---|---|
| Raspberry Pi 3 Model B+ | 5.0 V | 500 – 1000 mA | 2.50 A | 2.50 – 5.00 W |
| ESP32-S2 Mini | 3.3 V / 5.0 V | 70 – 100 mA | 310 mA | 0.23 – 0.50 W |
| Cámara USB (1080p) | 5.0 V | 100 – 250 mA | 300 mA | 0.50 – 1.25 W |
| Sensor ToF VL53L0X | 3.0 – 5.0 V | 19 mA | 40 mA | 0.06 W |
| IMU MPU-6050 | 3.3 – 5.0 V | 3.8 mA | 5 mA | 0.012 W |
| Servomotor MG90S | 4.8 – 6.0 V | 100 – 300 mA | 700 – 800 mA | 0.50 – 1.50 W |
| Micromotor DC 130 | 3.0 – 6.0 V | 150 – 250 mA | 0.80 – 1.20 A | 0.75 – 1.50 W |
| Driver Puente H TB6612FNG | 2.7–5.5 V / 15.0 V| 3 mA | 1.20 A (por canal)| Variable |
| Conversor Buck Step-Down 5V | 6.0 – 32.0 V | 10 – 20 mA *(quiescente) | 3.00 A (máx.) |η ≈ 90% – 95% |
| Regulador Lineal LM7805 | 7.0 – 25.0 V | 5 mA *(quiescente)* | 1.50 A | Variable |

<p align="right">
  <a href="#top">Back To Top</a>
</p>

--- 

## 4. 📐Arquitectura de software y estrategia para obstáculos

En esta competición hay dos retos:

- El **Desafío abierto** consiste en que el robot complete tres vueltas completas al circuito sin tocar la pared. Las dimensiones de cada lado del circuito y la dirección en la que circula el coche se determinan al azar.
- El **Desafío con obstáculos** exige que el robot complete tres vueltas evitando las señales de tráfico. Si la señal es roja, el robot debe circular por el lado derecho; si es verde, debe circular por el lado izquierdo. La dirección en la que circula el carrito y la ubicación de las señales se determinan al azar. Tras la tercera vuelta, el carrito debe encontrar la zona del estacionamiento y estacionarse en ella sin tocar las barreras que la rodean.

Nuestra implementación se basa en gran parte en los sensores y cámara para realizar un escaneo continuo del entorno, lo que ayuda al algoritmo a determinar el movimiento del robot.

Dividimos la estrategia en tres fases:

- Desafío abierto
- Desafío de obstáculos
- Maniobra de estacionamiento en paralelo

---

### 4.1 Reto abierto

El Desafío Abierto requiere que el robot complete tres vueltas alrededor de la arena sin tocar las paredes. La dirección de conducción es aleatoria al inicio, por lo que no es factible depender de movimientos preprogramados.

El robot determina en qué dirección girar analizando las paredes detectadas a su alrededor, el algoritmo funciona de la siguiente manera:

Al arrancar, el robot inicia una fase breve de avance recto y alineación para estabilizar su trayectoria dentro del carril. Mientras avanza, lee continuamente sus sensores de distancia en abanico y aplica un filtro a los datos para eliminar cualquier lectura errónea o ruido mecánico.

Con estas lecturas filtradas, el robot calcula en tiempo real la diferencia de espacio que tiene entre la pared izquierda y la pared derecha. Si se desplaza más hacia un lado, ajusta de inmediato la inclinación de sus ruedas delanteras para mantenerse siempre navegando por el centro exacto del carril. Al mismo tiempo, monitorea la distancia con la pared que tiene enfrente; a medida que la pared frontal se acerca, el robot reduce progresivamente su velocidad para aproximarse a la curva de forma controlada y sin riesgo de colisión.

Durante los primeros segundos de recorrido, el robot busca identificar la primera esquina. Tan pronto como el sensor central detecta que la pared de enfrente está lo suficientemente cerca, el robot frena temporalmente y evalúa su entorno para tomar una decisión:

1. Compara el espacio disponible a su derecha contra el espacio disponible a su izquierda.

2. Si la distancia medida hacia el lado derecho es mayor que hacia la izquierda, el robot deduce que el camino libre continúa hacia la derecha, por lo que determina que el circuito debe recorrerse en **sentido horario**.

3. De lo contrario, si encuentra más espacio libre a la izquierda, establece que el circuito se recorrerá en **sentido antihorario**.

Una vez memorizado el sentido de la pista, el robot ejecuta la maniobra de giro girando sus ruedas por completo hacia la dirección seleccionada y avanzando a una velocidad constante durante el tiempo necesario para superar el vértice de la esquina. 

Al terminar de dar la curva, el robot regresa automáticamente a su modo de centrado continuo, ajustando su dirección y velocidad en las rectas hasta encontrarse con las siguientes esquinas y completar con éxito las tres vueltas requeridas.

[Toca aquí para ver los diagramas de flujo](<Design process/Code process>)

### 4.2 Reto de osbtáculos

---

### 4.3 Estacionamiento en paralelo

<p align="right">
  <a href="#top">Back To Top</a>
</p>

---

## 5. ⚙Pensamiento sistémico y decisiones de ingeniería

### 5.1 Lenguajes de programación

#### Arduino IDE

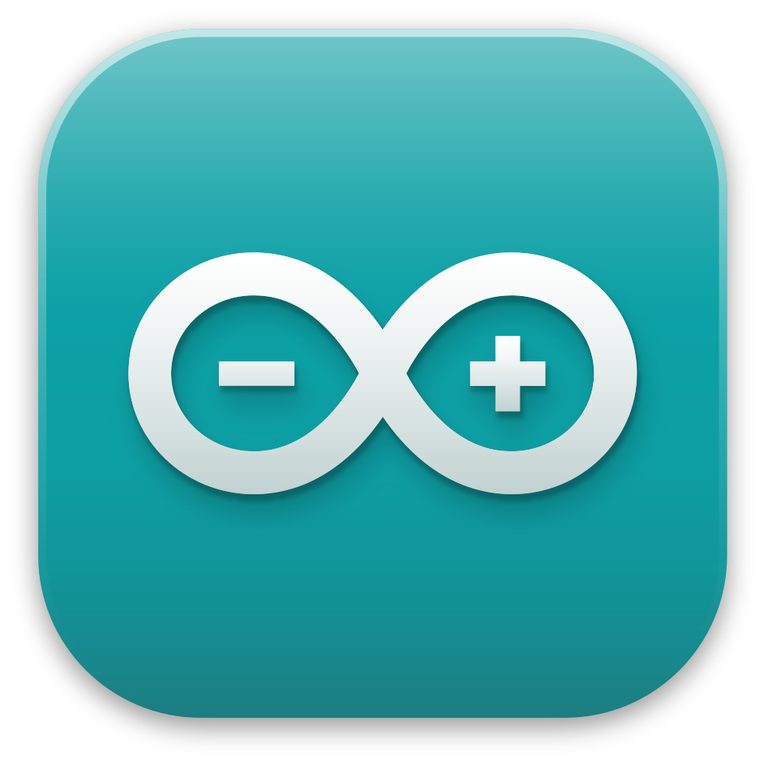
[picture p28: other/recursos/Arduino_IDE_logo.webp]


Al principio utilizamos Arduino IDE para programar la ESP32-S2 Mini de Eva01 durante el primer desafío. Sin embargo, no tomamos en cuenta que la comunicación serie y la integración con la Raspberry Pi 3 Model B+ resultaría compleja bajo este enfoque.

La Raspberry Pi 3 B+ ejecuta un sistema operativo completo (Raspberry Pi OS) y trabaja principalmente en Python, mientras que el código compilar con Arduino IDE está escrito en C/C++ (C++ simplificado). Esta disparidad exigía implementar protocolos de comunicación serie (UART o USB-CDC) con librerías adicionales como pyserial para parsear, estructurar y sincronizar constantemente las tramas de datos entre ambos entornos.

Además, la arquitectura nativa en C/C++ generaba barreras al intentar modificar o depurar algoritmos al vuelo durante las pruebas del robot. El cambio hacia un entorno unificado basado en Python / MicroPython facilitó la interacción, ya que ambos sistemas pueden compartir lógica, estructuras de datos y protocolos sin la necesidad de traducir el flujo entre dos lenguajes de programación distintos.

[Toca aquí para ver el código del primer desafío en Arduino](<src/Arduino IDE>)

#### Thonny 

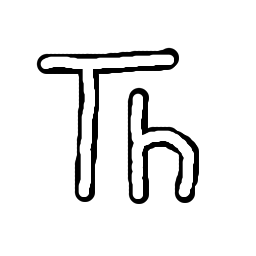
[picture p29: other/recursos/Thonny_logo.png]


Thonny es un Entorno de Desarrollo Integrado (IDE) gratuito y de código abierto diseñado específicamente para programar en Python y MicroPython de manera sencilla. Viene preinstalado de fábrica en el sistema operativo Raspberry Pi OS, por lo que es la herramienta que estamos utilizando actualmente en la Raspberry Pi 3 Model B+ y la ESP32 S2 Mini.

Su principal ventaja es que cuenta con un soporte integrado para gestionar una amplia variedad de librerías y conectarse directamente con microcontroladores. Esto nos permite redactar, ejecutar y depurar código en tiempo real dentro de un entorno nativo en Python, simplificando la comunicación entre la Raspberry Pi y la ESP32 S2 Mini sin las complicaciones de compatibilidad que teníamos con Arduino IDE.

[Toca aquí para ver el código del primer desafío en MicroPython](src/python)

---

### 5.2 Estructura del código
```text
├── main.py                     # Punto de entrada principal
├── Config.py                   # Ajustes globales y parámetros de hardware
│
├── 🚗 CAPA DE CONTROL DEL VEHÍCULO
│   └── Carro.py                # Clase principal que coordina actuadores, sensores y navegación
│
├── ⚙️ CAPA DE HARDWARE Y ACTUADORES
│   ├── Actuator.py             # Control de Servo (dirección) y Puente H TB6612FNG (tracción)
│   ├── SensorReader.py         # Gestión e inicialización de la red de 5 sensores VL53L0X
│   └── vl53l0x.py              # Driver I2C para el sensor de distancia VL53L0X
│
├── 🧠 CAPA DE ALGORITMOS Y NAVEGACIÓN
│   ├── PIDController.py        # Implementación genérica de un controlador PID
│   ├── SteeringPIDController.py# PID enfocado en el cálculo del ángulo de dirección
|   ├── Kalman.py               # Filtro de Kalman para fusión sensorial y reducir el ruido
│   └── Pista.py                # Lógica del entorno (sentido de giro y estado de la pista)
│
└── 📊 CAPA DE TELEMETRÍA Y LOGS (únicamente para pruebas)
    └── Logger.py               # Conexión Wi-Fi y envío de telemetría a Firebase
```

---

### 5.3 Instrucciones de compilación

#### Configuración de Firmware y Gestión de Flash (ESP32-S2 Mini)

**El problema del modo Bootloader (RST / B0) en Arduino IDE**

Al cargar desde Arduino IDE, el cargador de código estándar interactúa directamente con la memoria flash, sobrescribiendo la configuración del controlador USB OTG nativo del microcontrolador. Esto provoca que la placa quede atada al USB Download Bootloader por hardware. 

Como resultado, para poder subir cualquier cambio de código en Arduino IDE, es necesario realizar manualmente la secuencia de reinicio:
1. Mantener presionado el botón **B0 (GPIO0)**.
2. Presionar y soltar el botón **RST**.
3. Soltar el botón **B0**.

Este proceso repetitivo entorpece las pruebas rápidas en pista e incrementa el desgaste físico del hardware durante el desarrollo.

**Transición a MicroPython + Thonny IDE**

El cambio a MicroPython ejecutado sobre Thonny IDE nos permite aprovechar el canal USB CDC nativo de la ESP32-S2 Mini. Una vez que el firmware base de MicroPython está correctamente grabado en el chip, la placa gestiona la comunicación serial directamente con el entorno de desarrollo. Esto habilita la ejecución y transferencia de código automática sin necesidad de interactuar con los botones físicos.

**Proceso de restauración y configuración en Thonny IDE**

Para limpiar el estado guardado por Arduino IDE y dejar la ESP32-S2 lista para flasheo automático, se realiza el siguiente procedimiento dentro de Thonny:

1. Activación manual del Bootloader (Última vez)

Poner la tarjeta en modo de descarga manual manteniendo presionado **B0**, presionando/soltando **RST** y soltando **B0**.

2. Apertura del asistente de flasheo

En el menú superior de Thonny, acceder a `Herramientas` > `Opciones...` > pestaña `Intérprete`. Seleccionar el intérprete **MicroPython (ESP32)** y hacer clic en el enlace inferior **Instalar o actualizar MicroPython...**.

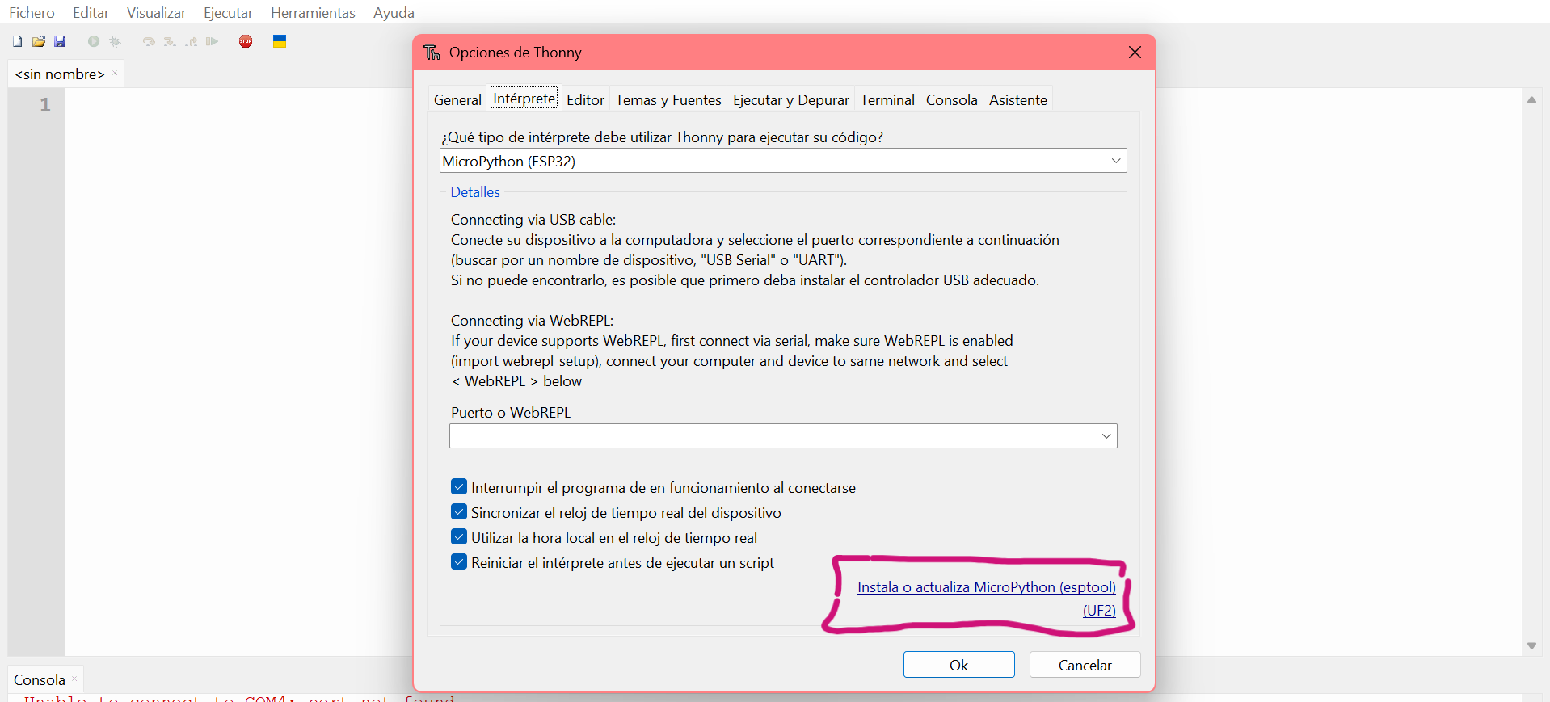
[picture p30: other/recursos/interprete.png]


3. Borrado de memoria y grabación de firmware

**En la ventana emergente de instalación:**

1. Target port: Seleccionar el puerto COM asignado a la placa.

2. Erase all flash before installing: Marcar la casilla obligatoriamente. Esto elimina la configuración previa cargada por el entorno de Arduino.

3. MicroPython family / variant: Seleccionar **ESP32-S2** / **Wemos S2 mini**.

4. Hacer clic en **Instalar**.

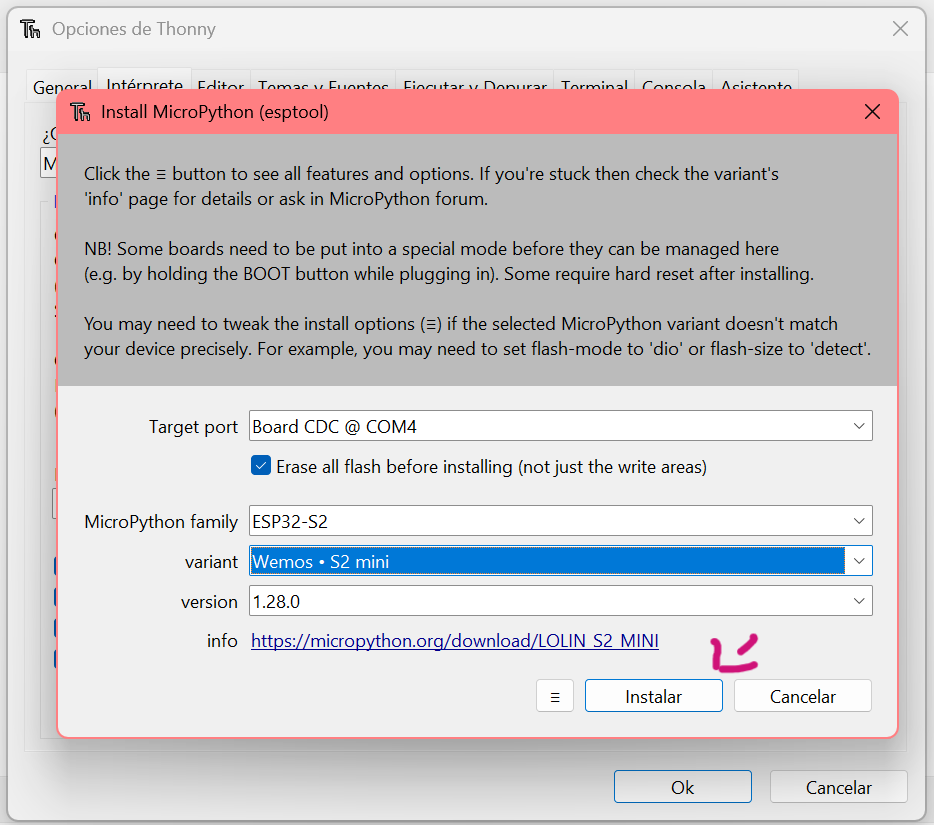
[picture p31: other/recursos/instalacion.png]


**Reinicio final**
Al completar la barra de progreso al 100%, cerrar las ventanas emergentes, presionar el botón **RST** una sola vez para arrancar el nuevo firmware e iniciar la comunicación por la consola de MicroPython.

<p align="right">
  <a href="#top">Back To Top</a>
</p>

---

## 6. 📝Lista de componentes

| Componente | Cantidad  |
|---|---|
| Raspberry Pi 3 B+ | 1 | 
| Esp32 S2 Mini | 1 |
| Sensores VL53L0X | 5 |
| MPU 6050 | 1 |
| Batería LiPo 7.4V 75C | 1 |
| Conversor Step Down 5v | 1 |
| Puente H tb6612fng | 1 |
| Switch | 1 |
| Cables unifilares | varios  |
| Conectores JST diferentes pines | varios  |
| Rodamientos 608 | 2 |
| Rodamientos 605 | 2 |
| Servo MG90S | 1 |
| Micro motor dc 130 3V - 6V | 1 |
| PerfBoard | 1 |
| Resistencias 1KΩ | 3 |
| Resistencias 220KΩ | 1 |
| Led | 1 |
| Regulador Lineal LM7805 | 1 |
| Capacitor 40 105 c | 1 |
| Capacitor cerámico 10uf | 1 |
| Conector xt60 | 1 |
| Conector DC Plug | 1 |
| Tornillos y tuercas: M3 y M4 | varios  |
| Borneras | 4 |
| Terminales | 4 |
| Espadines hembra/macho | varios  |
| Eje 5mm | 1 |
| Cámara 1080p | 1 |
| Filamento PETG | 1 |
| Filamento TPU | 1 |

**Impresoras utilizadas:**

- Creality Ender 3 V3 SE

<p align="right">
  <a href="#top">Back To Top</a>
</p>

---

## 7. 💎Archivos de modelos 3D

### 7.1 Archivos STL originales

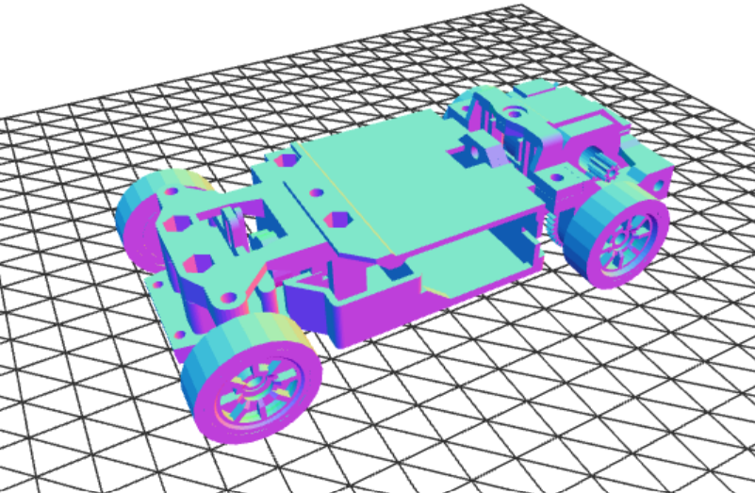
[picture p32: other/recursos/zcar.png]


*Estos archivos son extraídos directamente del repositorio proporcionado por "alexyo132" creador de zcar.*

[Toca aquí](models/zcar)

---

### 7.2 Archivos modificados Eva01

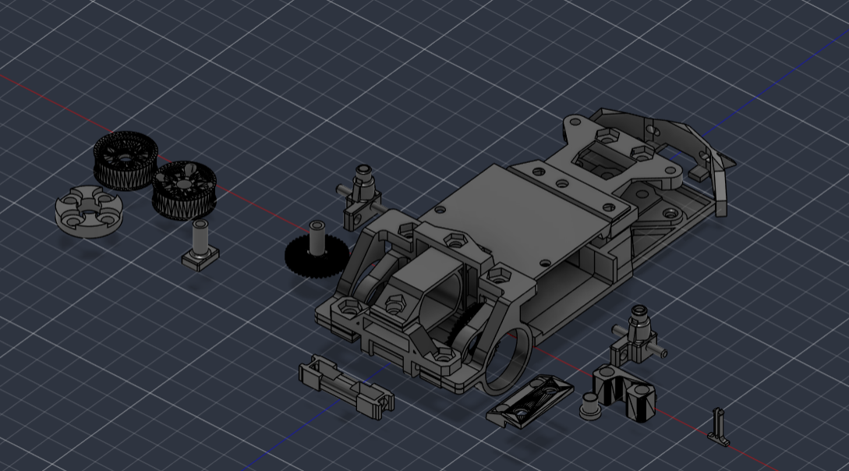
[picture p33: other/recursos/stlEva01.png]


[Toca aquí](models/Eva01)

<p align="right">
  <a href="#top">Back To Top</a>
</p>

---

## 8. 🛠️Instrucciones de montaje

Pronto

<p align="right">
  <a href="#top">Back To Top</a>
</p>

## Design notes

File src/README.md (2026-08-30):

# 🏎️ Eva 01 - Vehículo Autónomo (WRO Future Engineers)

Esta carpeta contiene el código fuente en MicroPython/Python diseñado para el vehículo autónomo **Eva 01**, configurado para abordar los desafíos de la competencia *World Robot Olympiad (WRO) Future Engineers*.

El sistema orquesta la gestión secuencial y lectura de sensores de distancia por tiempo de vuelo (ToF VL53L0X), el filtrado digital de datos, el control de tracción y dirección del chasis, y la transmisión de telemetría IoT en tiempo real.

---

## 📌 Inspiración y Créditos

Este proyecto toma como base conceptual, arquitectónica y de referencia el trabajo del repositorio **ichis-lab**:
* **Repositorio de Referencia:** (https://github.com/ichis-lab/minicar-battle) Módulo *seven*

* **Elementos Clave Adoptados y Adaptados:**

  - Direccionamiento I2C Dinámico (VL53L0X): Encendido secuencial utilizando pines `XSHUT` para reasignar la dirección I2C por defecto (`0x29`) de múltiples sensores al arrancar.

  - Control de Sensores (`set_address` y `set_offset`): Uso de una librería basada en Adafruit adaptada para MicroPython, que permite reasignar direcciones I2C al vuelo (registro `0x8A`) y calibrar el desfase físico en milímetros directamente en el registro `0x28`.
 
  - Arquitectura Modular del Vehículo: Organización del código dividida en clases independientes para la gestión de sensores, actuadores y estado general del vehículo.
  
  - Gestión de Modos de Ejecución: Uso de `Config.py` para alternar entre pruebas de banco, depuración y modo competencia.

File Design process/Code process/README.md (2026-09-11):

### Aquí podemos observar el proceso de nuestra estrategia de control mediante diagramas de flujo

**Evolución del Algoritmo de Control (Primer Desafío)**

A lo largo del desarrollo de Eva01, la estrategia de navegación fue adaptándose para optimizar la respuesta en tiempo real y mitigar fallos de medición.

- **Pure Pursuit**
Diseñado inicialmente para seguir geometrías de pista mediante cálculo de brecha libre (GapFinder) e interpolación de giros.

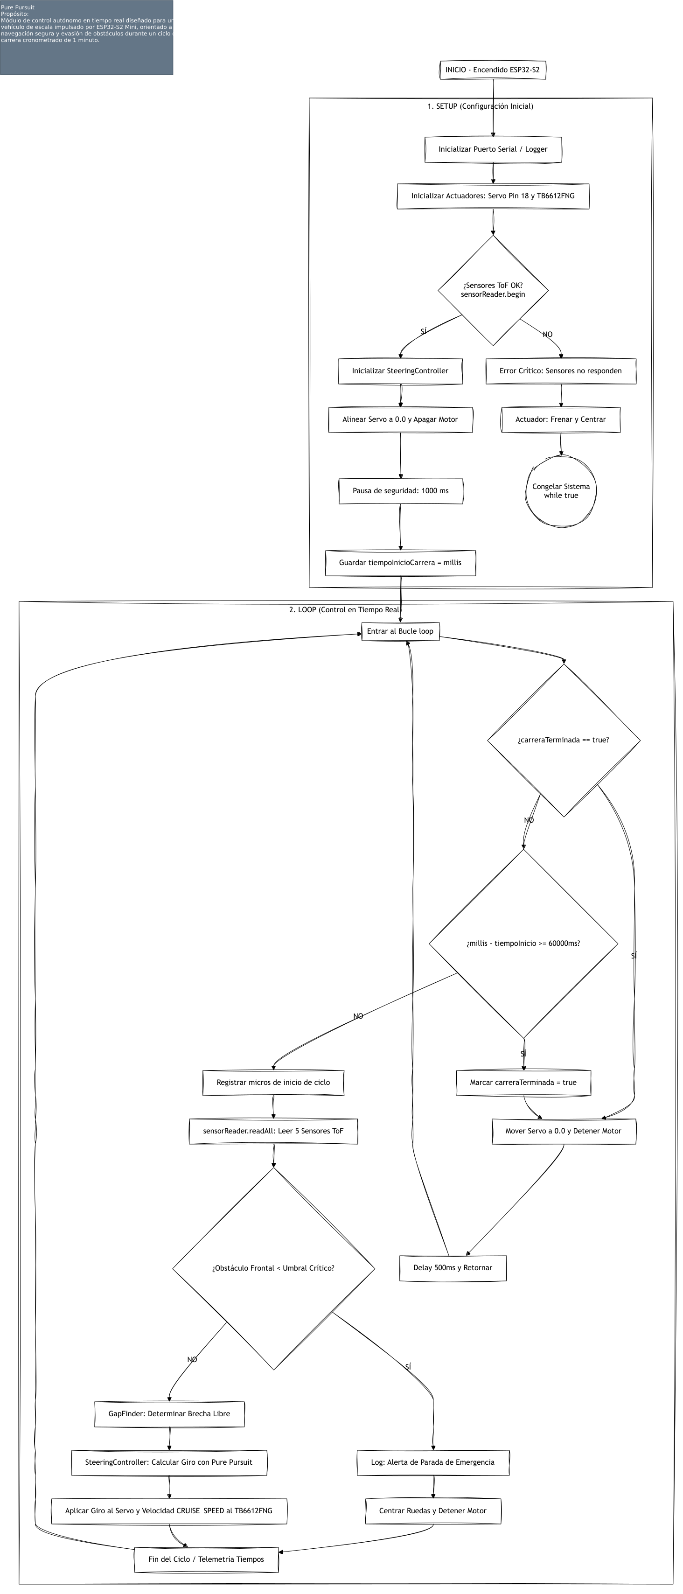
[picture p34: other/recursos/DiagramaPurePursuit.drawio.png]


**Motivo del cambio:** Aunque reaccionaba a los sensores ToF, dependía excesivamente de lecturas relativas inmediatas sin una noción de orientación global ni de la trayectoria completa del vehículo. Para resolver esto y tener una navegación orientada a waypoints, migramos hacia un sistema de coordenadas.

- **Sistema de coordenadas** [Ver código](<../../src/python/1st - Coordinate System>)
Implementado para una navegación global basada en waypoints ($x, y$) predefinidos e integración de datos del MPU (IMU) para completar el circuito de 3 vueltas.

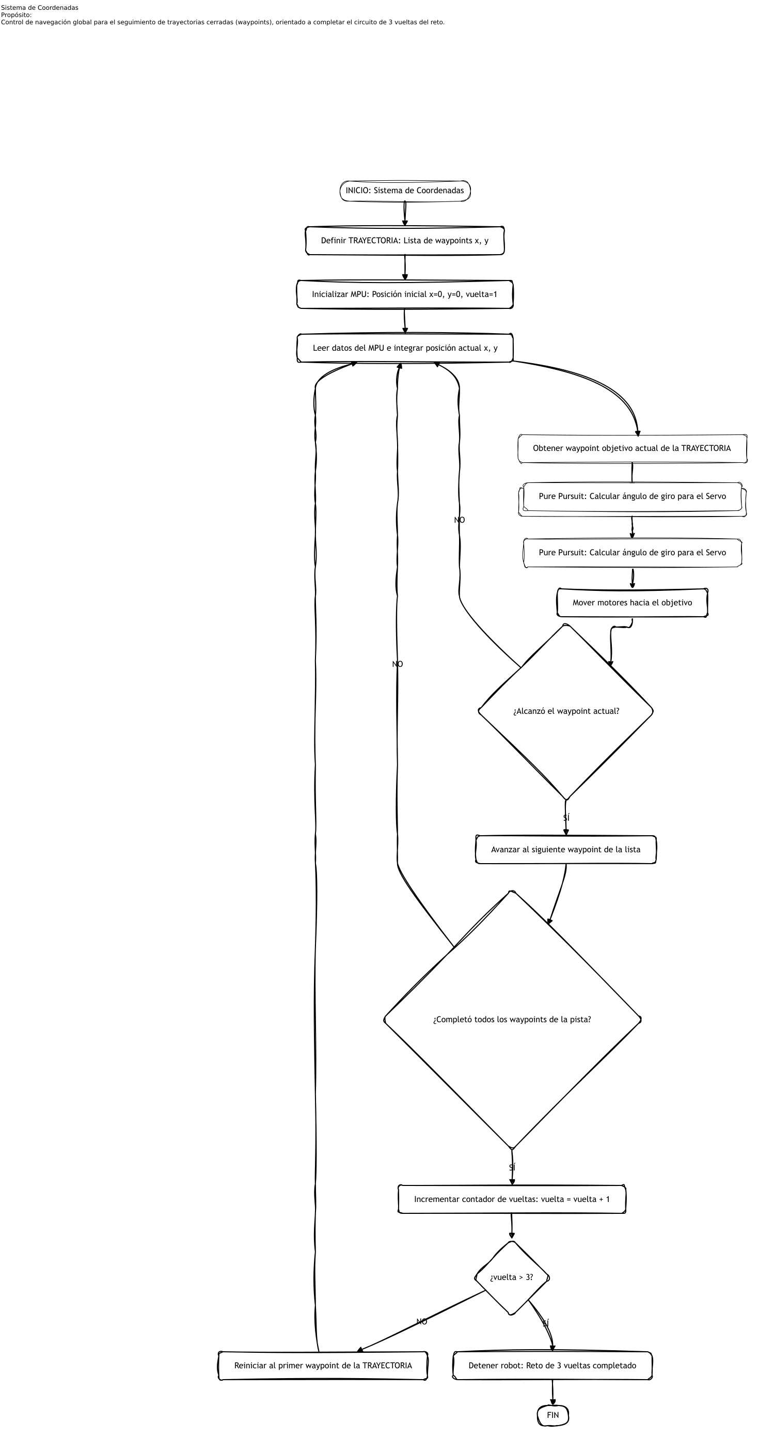
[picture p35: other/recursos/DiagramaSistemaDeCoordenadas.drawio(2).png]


**Motivo del cambio:** La integración constante de los datos del MPU generó derivas acumulativas en la estimación de la posición actual ($x,y$), provocando pérdidas de precisión tras varias iteraciones y lecturas erróneas al alcanzar los waypoints.

- **PID** [Ver código](<../../src/python/1st - PID>)
Controlador en bucle cerrado basado en realimentación directa en tiempo real ($K_p$, $K_i$, $K_d$) con Anti-windup e integración de delta de tiempo ($dt$).

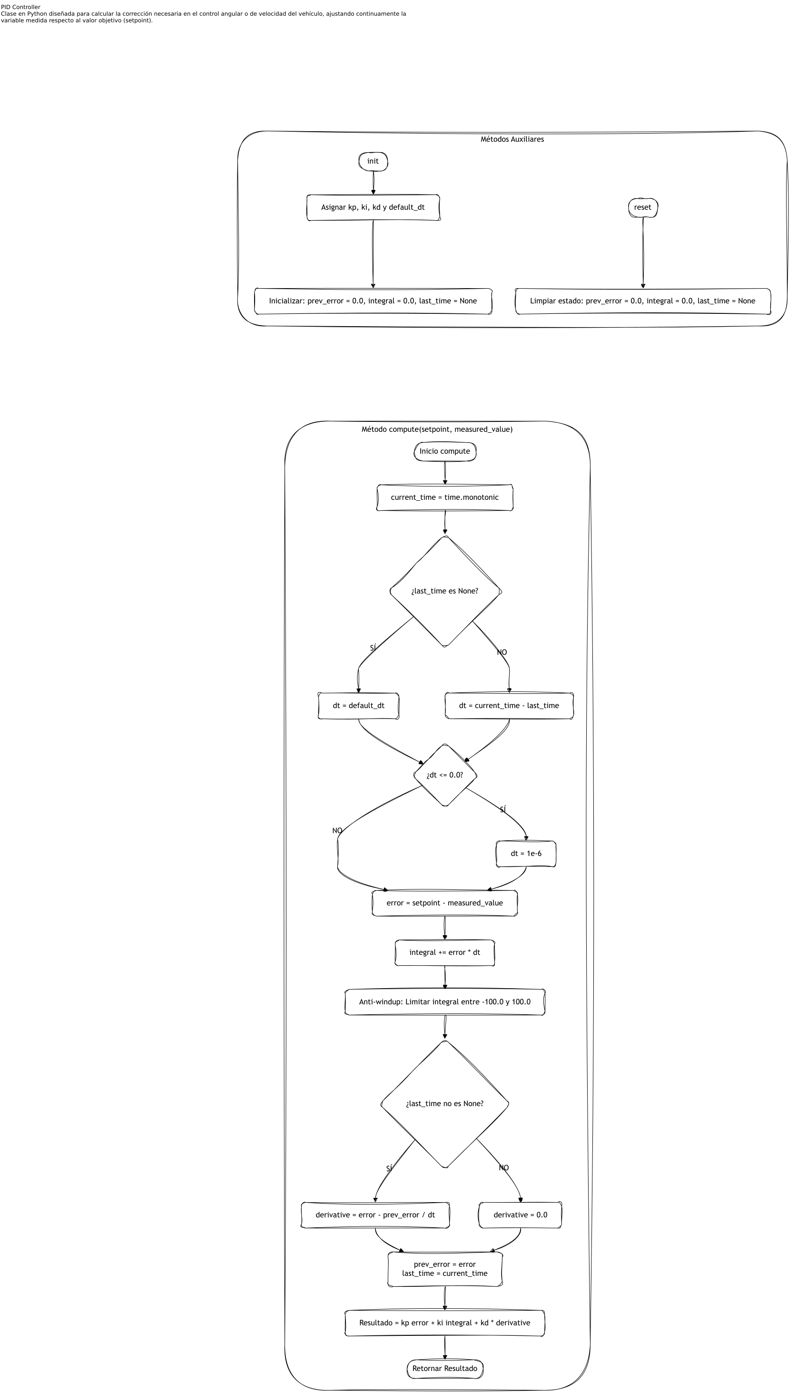
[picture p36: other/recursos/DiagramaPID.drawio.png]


**¿Por qué nos quedamos con PID?:**  Ofrece una corrección continua y reactiva al instante frente a las diferencias medidas ($error = setpoint - measured\_value$), eliminando la acumulación de error por integración de coordenadas globales y garantizando un control estable, ligero y preciso en el servo de dirección y la velocidad.

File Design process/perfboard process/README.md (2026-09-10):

Para integrar los sensores, el giroscopio y los actuadores (servomotor y motor de tracción), se desarrolló una placa de circuito adaptada a las necesidades del vehículo. El primer paso consistió en ensamblar el circuito en una protoboard para validar el funcionamiento conjunto de todos los componentes.

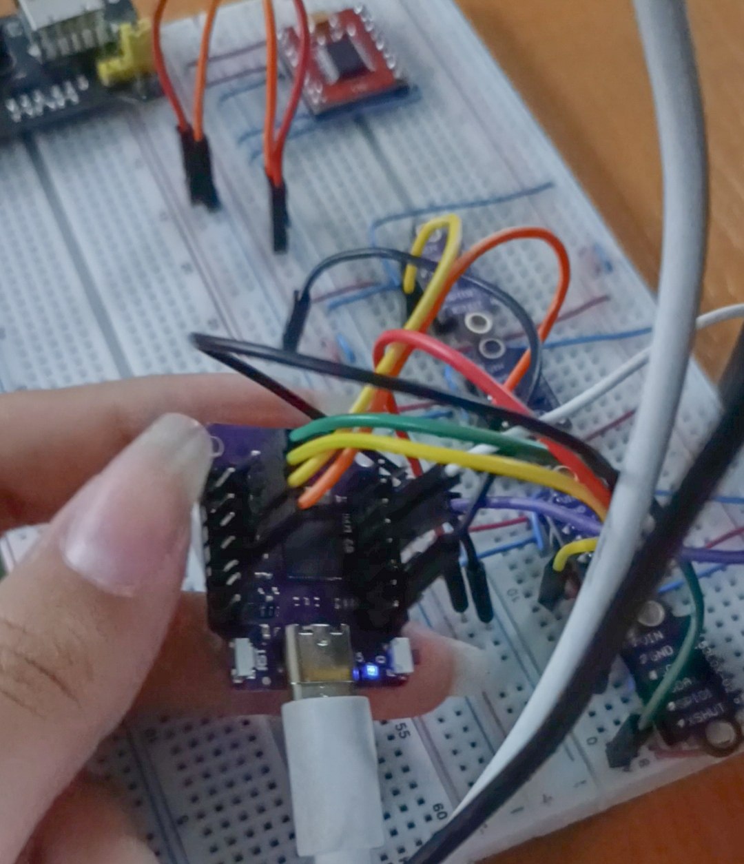
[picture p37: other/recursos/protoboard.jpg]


Se conectaron en paralelo las líneas de alimentación y comunicación (`GND`, `VIN`, `SDA` y `SCL`), mientras que los pines `X-SHUT` de los sensores ToF se asignaron de forma independiente a pines GPIO del ESP32-S2 Mini. Durante la fase de pruebas mediante software, se verificó la correcta detección del MPU-6050 y de cada sensor en el bus I2C junto con sus lecturas de datos. Tras validar el circuito, se procedió al montaje definitivo sobre una placa perforada (*perfboard*).

Para la fabricación se utilizaron los siguientes materiales:

| Componente | Cantidad |
|--- |---|
| Conectores JST  2 pines, Hembra-Macho  | 5 |
| Conectores JST  5 pines, Hembra-Macho  | 5 |
| Borneras de tornillo | 4 |
| Espadines macho 3 pines | 1 |
| Espadines hembra 8 pines | 5 |
| Cable coaxial | - |
| Cable de red UTP (pares trenzados) | - |
| Perfboard | 1 |

*(Se extrajeron los conductores internos de cobre de los cables de red y el núcleo central del cable coaxial para realizar las interconexiones eléctricas).*

El ensamblaje se realizó sobre la placa perforada mediante la técnica de soldadura manual punto a punto. Los componentes principales (espadines, conectores JST y borneras) se fijaron en la cara superior, mientras que las interconexiones eléctricas, buses de alimentación y señales de control se enrutaron mayoritariamente por la cara posterior, soldando conductores de cobre rígido e hilos unifilares a cada terminal correspondiente.

### Circuito Terminado

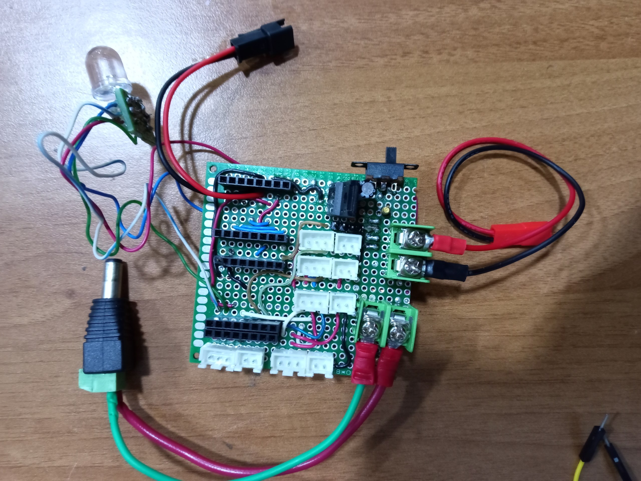
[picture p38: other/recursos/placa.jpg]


### Reverso del Circuito

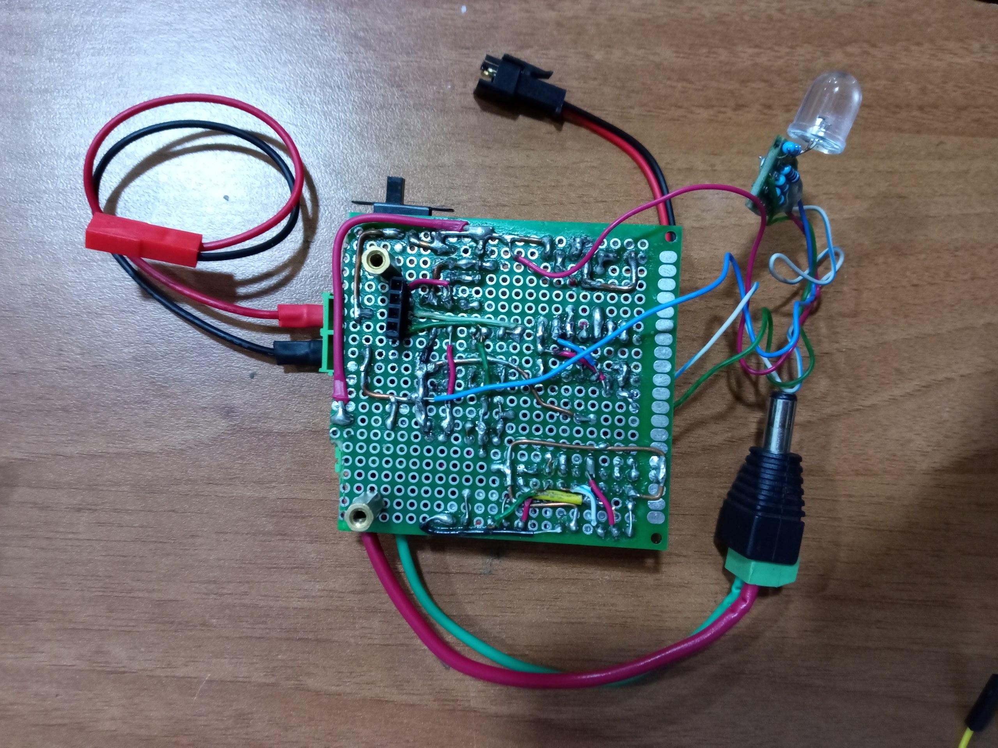
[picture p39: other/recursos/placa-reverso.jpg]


> ℹ️ *Para consultar el esquema de conexiones detallado, dirígete al apartado de [Diagramas Eléctricos](../../README.md#34-diagramas-eléctricos).*

### Distribución y Orden de los Sensores

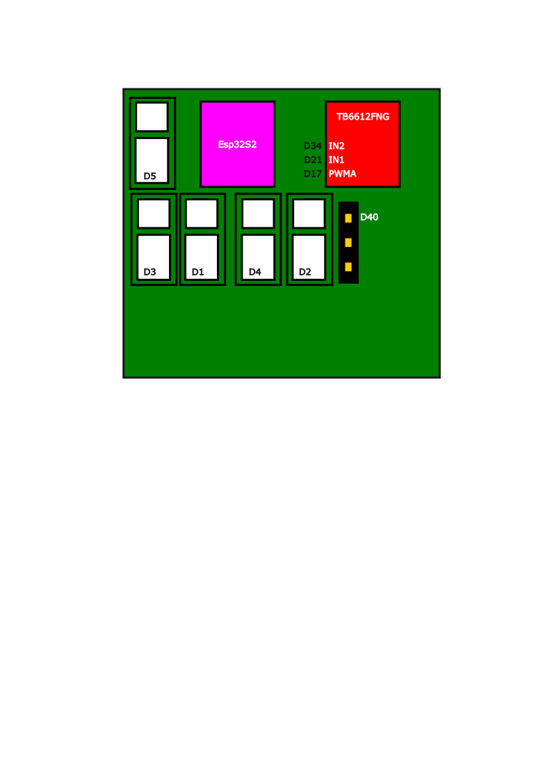
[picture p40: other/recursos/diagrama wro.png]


La numeración del 1 al 5 representa la posición física de los sensores en el soporte impreso en 3D (ordenados de izquierda a derecha según el sentido de marcha). Las etiquetas **D1 a D5** del diagrama corresponden a los conectores en la placa donde van conectados cada uno.

### Consideraciones Técnicas sobre la Placa 

Al tratarse de una placa de circuito perforada ensamblada manualmente (sin grabado de pistas ni fabricación CNC), las uniones soldadas son más susceptibles al desgaste mecánico o a falsos contactos. Ante cualquier falla en el circuito, se recomienda verificar la continuidad de las líneas y los niveles de voltaje mediante un multímetro. Como mejora para futuras iteraciones, se planea el diseño y la fabricación de un PCB personalizado en fábrica para garantizar mayor estabilidad y robustez estructural.

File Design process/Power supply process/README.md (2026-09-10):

## Aquí podemos encontrar la evolución de nuestra fuente de energía

### Pruebas Iniciales de Alimentación y Sistema de Potencia

Al principio, nuestra opción de alimentación fue una batería de **litio de 3.7V y 1000 mAh**. Realizamos pruebas sencillas conectando la batería directamente a los motores y al controlador, pero notamos de inmediato que el Eva01 carecía de la fuerza y la velocidad necesarias para desplazarse adecuadamente.

Al analizar el comportamiento del circuito, identificamos los siguientes factores técnicos que afectaban el rendimiento:

**Limitación de corriente del módulo IP5306:** Utilizamos un módulo cargador/elevador para Power Bank (basado en el chip IP5306) para regular la salida de la batería a 5V. Sin embargo, este integrado está diseñado para electrónica de bajo consumo y carga de dispositivos, no para cargas inductivas. Al exigir torque a los motores, la corriente de arranque (inrush current) superaba el límite del módulo, activando sus protecciones internas y provocando caídas drásticas de tensión.

**Pérdida de eficiencia por doble regulación:** Intentar elevar los 3.7V de la celda a 5V con el módulo IP5306, para luego conectarlo al regulador elevador XL6019 e incrementar aún más la tensión, generó un cuello de botella energético considerable debido a las pérdidas acumuladas por conversión de potencia.

**Tasa de descarga de la batería:** La celda LiPo de 1000 mAh de una sola celda (1S) no lograba suministrar la tasa de descarga necesaria para mantener un flujo de corriente estable bajo demanda de carga mecánica.

**Picos de consumo por el servomotor:** Los servomotores generan picos de corriente (current spikes) al moverse bruscamente bajo carga mecánica. En esta etapa inicial, al compartir la misma línea débil de 5V proveniente del IP5306 con el microcontrolador y el puente H, los tirones de consumo del servo provocaban caídas de voltaje (brownouts) que reiniciaban la placa de control o hacían temblar la dirección por falta de potencia.

### Diagrama de Conexión Utilizado en las Pruebas

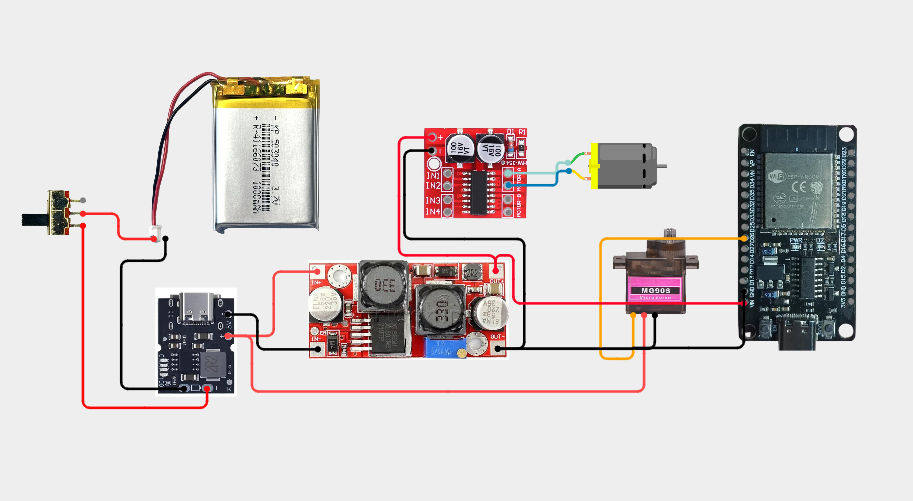
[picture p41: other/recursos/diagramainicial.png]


Debido a estas caídas drásticas de voltaje y los reinicios del sistema al exigir tracción a los motores y movimiento a la dirección, descartamos esta configuración e iniciamos el rediseño del sistema de alimentación hacia una fuente con mayor capacidad de descarga y respuesta en corriente.

### Vídeo demostrativo

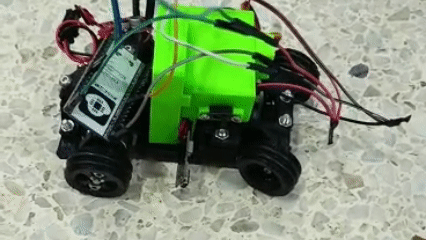
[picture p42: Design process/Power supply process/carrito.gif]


> ℹ️ *Para visualizar nuestra siguiente opción, dirígete al apartado de [Fuente de alimentación](../../README.md#31-fuente-de-alimentación).*

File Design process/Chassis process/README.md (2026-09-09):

### Optimización del chasis⭐️

La primera modificación durante el desarrollo del chasis del «zcar» consistió en rediseñar el modelo en Fusion 360 para adaptar los puntos de montaje a componentes más fáciles de conseguir en el mercado local. Para ello, se modificaron los orificios del archivo .stl original con el fin de sustituir los tornillos y tuercas M3 por otros de tamaño M4.

Sin embargo, las pruebas iniciales de impresión revelaron que al aumentar el diámetro de los orificios se reducía drásticamente el grosor de las paredes en las zonas del eje de dirección y del eje motriz, lo que comprometía la resistencia estructural frente a las tensiones mecánicas.

Para resolver este problema sin sacrificar la ventaja de utilizar componentes disponibles localmente, se adoptó un diseño híbrido: se mantuvieron los soportes M4 para la estructura principal del vehículo, mientras que los componentes M3 se reservaron exclusivamente para el eje de dirección y el eje motriz con el fin de preservar su integridad geométrica. Además, se aumentó el espesor del eje motriz y se reforzó el soporte del eje trasero.

Se modificó la pieza que limitaba el recorrido del mecanismo de dirección. Esta mejora resultó crucial, ya que permitió aumentar el ángulo de giro máximo del robot, optimizando significativamente su rendimiento y maniobrabilidad en la pista.

Un cambio clave en este proceso fue la sustitución del eje motriz incluido en el archivo .stl original de «zcar» por uno metálico.



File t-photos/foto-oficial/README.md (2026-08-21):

# Foto Oficial del Equipo
2afa2ad2-66f1-48aa-bc96-628adb1001fa

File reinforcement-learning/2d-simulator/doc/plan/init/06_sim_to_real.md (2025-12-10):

# Sim-to-Real転移戦略

## 1. 概要

シミュレーターで学習したポリシーを実機に転移する際の課題と対策をまとめる。

### 1.1 主要な課題

1. **物理パラメータの違い**
   - 摩擦係数、質量、慣性の不一致
   - モーター応答の遅延
   - タイヤのスリップ

2. **センサーノイズ**
   - LiDARの測定誤差
   - IMUのドリフト
   - レイテンシ（遅延）

3. **環境の違い**
   - 床面の状態（摩擦の変動）
   - 照明（LiDARには影響少）
   - 温度（モーター性能への影響）

4. **制御の違い**
   - 離散時間制御（サンプリング周波数）
   - アクチュエータの限界
   - 通信遅延

---

## 2. Domain Randomization戦略

### 2.1 物理パラメータのランダム化

学習時に以下のパラメータをエピソードごとにランダム化：

#### 摩擦係数
```python
friction_coefficient = np.random.uniform(0.5, 1.5)
# 理由: 床面の状態は変動する（ホコリ、湿度等）
```

#### 質量・慣性
```python
mass = base_mass * np.random.uniform(0.8, 1.2)
# 理由: バッテリー残量、パーツの取り付け誤差
```

#### モーター応答遅延
```python
motor_delay = np.random.uniform(0.0, 0.05)  # 0-50ms
# 理由: PWM制御、モーターの立ち上がり時間
```

#### モータートルクの変動
```python
motor_force = nominal_force * np.random.uniform(0.9, 1.1)
# 理由: 個体差、バッテリー電圧の変動
```

### 2.2 センサーノイズのランダム化

#### LiDARノイズ
```python
def add_lidar_noise(distances, noise_config):
    # ガウシアンノイズ
    noise_level = np.random.uniform(
        noise_config['min_noise'],
        noise_config['max_noise']
    )
    noise = np.random.normal(0, noise_level * max_range, distances.shape)
    noisy_distances = distances + noise

    # ドロップアウト（一部のレイが無効）
    dropout_prob = noise_config['dropout_prob']
    mask = np.random.random(distances.shape) > dropout_prob
    noisy_distances = np.where(mask, noisy_distances, max_range)

    # スパイクノイズ（外れ値）
    spike_prob = noise_config['spike_prob']
    spike_mask = np.random.random(distances.shape) < spike_prob
    noisy_distances = np.where(spike_mask, np.random.uniform(0, max_range), noisy_distances)

    return np.clip(noisy_distances, 0, max_range)
```

**推奨設定:**
```yaml
lidar_noise:
  min_noise: 0.005  # 距離の0.5%
  max_noise: 0.02   # 距離の2%
  dropout_prob: 0.05  # 5%のレイが無効
  spike_prob: 0.01    # 1%のレイが外れ値
```

#### IMUノイズ
```python
# 角速度ノイズ
angular_velocity_noisy = angular_velocity + np.random.normal(0, 0.01)

# ドリフト（長期的なバイアス）
imu_bias += np.random.normal(0, 0.0001)
angular_velocity_noisy += imu_bias
```

### 2.3 遅延のシミュレーション

#### センサー遅延
```python
class DelayedSensor:
    def __init__(self, delay_steps: int):
        self.delay_steps = delay_steps
        self.history = deque(maxlen=delay_steps + 1)

    def get_observation(self, current_obs):
        self.history.append(current_obs)
        if len(self.history) <= self.delay_steps:
            return current_obs  # 初期は遅延なし
        return self.history[0]  # 古い観測を返す
```

#### 制御遅延
```python
class DelayedActuator:
    def __init__(self, delay_steps: int):
        self.delay_steps = delay_steps
        self.action_queue = deque(maxlen=delay_steps + 1)

    def apply_action(self, action):
        self.action_queue.append(action)
        if len(self.action_queue) <= self.delay_steps:
            return np.zeros_like(action)  # 初期は動かない
        return self.action_queue[0]  # 古い行動を適用
```

**推奨設定:**
```yaml
delays:
  sensor_delay_steps: 1-2   # 10-20Hz → 50-100ms
  actuator_delay_steps: 1-2
```

---

## 3. 実機セットアップ

### 3.1 ハードウェア構成

#### Raspberry Pi 4のセットアップ
```bash
# OS: Raspberry Pi OS (64-bit)
# Python 3.9以上

# 必要なライブラリ
sudo apt-get update
sudo apt-get install -y python3-pip python3-opencv
pip3 install numpy onnxruntime
```

#### LiDAR接続
```python
# LD06 LiDARのセットアップ
import serial

class LD06LiDAR:
    def __init__(self, port='/dev/ttyUSB0', baudrate=230400):
        self.serial = serial.Serial(port, baudrate)

    def read_scan(self) -> np.ndarray:
        """1回転分のスキャンを読み取り"""
        # LD06のプロトコルに従ってパース
        ...
        return distances  # (360,) または (72,) にリサンプル
```

#### モーター制御
```python
import RPi.GPIO as GPIO
import pigpio

class MotorController:
    def __init__(self, pwm_pin_throttle, pwm_pin_steering):
        self.pi = pigpio.pi()
        self.throttle_pin = pwm_pin_throttle
        self.steering_pin = pwm_pin_steering

    def set_throttle(self, value: float):
        """スロットル設定 (0~1)"""
        pwm = int(1000 + value * 1000)  # 1000-2000us
        self.pi.set_servo_pulsewidth(self.throttle_pin, pwm)

    def set_steering(self, value: float):
        """ステアリング設定 (-1~1)"""
        pwm = int(1500 + value * 500)  # 1000-2000us
        self.pi.set_servo_pulsewidth(self.steering_pin, pwm)
```

### 3.2 モデルのデプロイ

#### PyTorch → ONNX変換
```python
# src/deploy/model_converter.py

def convert_to_onnx(policy_path: str, output_path: str):
    # モデルをロード
    policy = GaussianPolicy(obs_dim=77, action_dim=2)
    policy.load_state_dict(torch.load(policy_path))
    policy.eval()

    # ダミー入力
    dummy_input = torch.randn(1, 77)

    # ONNX変換
    torch.onnx.export(
        policy,
        dummy_input,
        output_path,
        export_params=True,
        opset_version=11,
        input_names=['observation'],
        output_names=['action_mean', 'action_log_std'],
        dynamic_axes={
            'observation': {0: 'batch_size'},
            'action_mean': {0: 'batch_size'},
            'action_log_std': {0: 'batch_size'},
        }
    )
    print(f"Model exported to {output_path}")
```

#### ONNX Runtime推論
```python
# src/deploy/rpi_inference.py

import onnxruntime as ort

class ONNXPolicy:
    def __init__(self, model_path: str):
        self.session = ort.InferenceSession(model_path)
        self.input_name = self.session.get_inputs()[0].name

    def predict(self, observation: np.ndarray) -> np.ndarray:
        """
        Args:
            observation: (77,)
        Returns:
            action: (2,) [steering, throttle]
        """
        obs = observation.reshape(1, -1).astype(np.float32)
        outputs = self.session.run(None, {self.input_name: obs})

        action_mean = outputs[0][0]  # (2,)
        # 実機では平均値を使用（探索なし）
        return action_mean
```

### 3.3 実機制御ループ
```python
# scripts/run_real_robot.py

def main():
    # ハードウェア初期化
    lidar = LD06LiDAR()
    motor = MotorController(pwm_pin_throttle=18, pwm_pin_steering=19)

    # ポリシーロード
    policy = ONNXPolicy("models/best/policy.onnx")

    # 状態保持
    last_action = np.zeros(2)
    velocity = np.zeros(2)

    # 制御ループ (20Hz)
    rate = 20  # Hz
    dt = 1.0 / rate

    while True:
        start_time = time.time()

        # センサー読み取り
        lidar_scan = lidar.read_scan()  # (72,)

        # 速度推定（簡易的）
        velocity = estimate_velocity()  # IMUまたはオドメトリから

        # 観測作成
        observation = np.concatenate([
            lidar_scan,
            velocity,
            [0.0],  # 角速度（IMUから取得）
            last_action,
        ])

        # 推論
        action = policy.predict(observation)

        # 制御適用
        motor.set_steering(action[0])
        motor.set_throttle(action[1])

        last_action = action

        # 周期維持
        elapsed = time.time() - start_time
        time.sleep(max(0, dt - elapsed))
```

---

## 4. 実機キャリブレーション

### 4.1 センサーキャリブレーション

#### LiDARキャリブレーション
```python
def calibrate_lidar():
    """LiDARのオフセットとスケールを調整"""
    # 既知の距離に壁を設置
    true_distances = [1.0, 2.0, 3.0, 5.0]  # m

    measured_distances = []
    for true_dist in true_distances:
        input(f"壁を{true_dist}mに設置してEnter")
        scan = lidar.read_scan()
        measured_distances.append(np.median(scan))

    # 線形回帰でスケールとオフセットを求める
    from scipy.stats import linregress
    slope, intercept, _, _, _ = linregress(measured_distances, true_distances)

    print(f"Scale: {slope}, Offset: {intercept}")
    return slope, intercept

# 使用時
lidar_scan_calibrated = lidar_scan * scale + offset
```

#### IMUキャリブレーション
```python
def calibrate_imu(num_samples=1000):
    """静止状態でIMUのバイアスを測定"""
    gyro_readings = []

    print("車両を静止させてください...")
    time.sleep(2)

    for _ in range(num_samples):
        gyro = imu.read_gyro()
        gyro_readings.append(gyro)
        time.sleep(0.01)

    bias = np.mean(gyro_readings, axis=0)
    print(f"Gyro bias: {bias}")
    return bias
```

### 4.2 モーターキャリブレーション

#### スロットル応答の測定
```python
def calibrate_throttle():
    """スロットル入力と実際の速度の関係を測定"""
    throttle_inputs = np.linspace(0, 1, 10)
    measured_speeds = []

    for throttle in throttle_inputs:
        motor.set_throttle(throttle)
        time.sleep(2)  # 安定するまで待機

        # 速度測定（オドメトリまたは外部計測）
        speed = measure_speed()
        measured_speeds.append(speed)

        motor.set_throttle(0)
        time.sleep(1)

    # プロット
    plt.plot(throttle_inputs, measured_speeds)
    plt.xlabel('Throttle Input')
    plt.ylabel('Speed (m/s)')
    plt.savefig('throttle_calibration.png')
```

#### ステアリング応答の測定
```python
def calibrate_steering():
    """ステアリング入力と旋回半径の関係を測定"""
    steering_inputs = np.linspace(-1, 1, 10)
    turn_radii = []

    for steering in steering_inputs:
        motor.set_steering(steering)
        motor.set_throttle(0.5)

        # 円を描いて旋回半径を測定
        radius = measure_turn_radius()
        turn_radii.append(radius)

        motor.set_throttle(0)
        time.sleep(1)

    plt.plot(steering_inputs, turn_radii)
    plt.xlabel('Steering Input')
    plt.ylabel('Turn Radius (m)')
    plt.savefig('steering_calibration.png')
```

---

## 5. 段階的な転移プロセス

### Phase 1: シミュレーターの調整
1. 実機でセンサーデータを収集
2. シミュレーターのパラメータを実機に近づける
3. Domain Randomizationの範囲を調整

### Phase 2: 安全な環境でテスト
1. 広いスペースでゆっくり走行
2. 衝突しても安全な環境
3. ポリシーの動作を観察

### Phase 3: Fine-tuning（オプション）
1. 実機で追加学習（少量のエピソード）
2. シミュレーター + 実機のハイブリッド学習
3. ポリシーの微調整

### Phase 4: 本番環境でのテスト
1. 実際のコースで評価
2. 複数回のトライアル
3. 安定性の確認

---

## 6. トラブルシューティング

### 6.1 実機での一般的な問題

#### 問題1: 実機で動きが不安定
**原因:**
- センサーノイズが想定より大きい
- 制御周波数が不足
- モーター応答が遅い

**対策:**
```python
# センサーデータの移動平均
lidar_scan = moving_average(lidar_scan, window=3)

# 制御周波数を上げる
rate = 30  # 20Hz → 30Hz

# モーターの最大トルクを制限
max_throttle = 0.7  # 1.0 → 0.7
```

#### 問題2: 壁に衝突する
**原因:**
- LiDARの精度不足
- 安全マージンが小さい
- 遅延の影響

**対策:**
```python
# 安全マージンを増やす
def add_safety_margin(action, min_distance):
    if min_distance < 0.5:  # 50cm以内
        # スロットルを減らす
        action[1] *= 0.5
    return action
```

#### 問題3: 推論速度が遅い
**原因:**
- モデルサイズが大きい
- ONNX Runtimeの最適化不足

**対策:**
```python
# ONNX Runtimeの最適化
session_options = ort.SessionOptions()
session_options.graph_optimization_level = ort.GraphOptimizationLevel.ORT_ENABLE_ALL
session = ort.InferenceSession(model_path, session_options)

# モデルの軽量化
# - ネットワークサイズを削減（256→128）
# - 量子化（FP32 → FP16 or INT8）
```

### 6.2 安全対策

#### 緊急停止機能
```python
class EmergencyStop:
    def __init__(self, min_safe_distance=0.2):
        self.min_safe_distance = min_safe_distance

    def should_stop(self, lidar_scan) -> bool:
        """緊急停止が必要か判定"""
        min_distance = np.min(lidar_scan)
        return min_distance < self.min_safe_distance

# 使用
emergency_stop = EmergencyStop()
if emergency_stop.should_stop(lidar_scan):
    motor.set_throttle(0)
    motor.set_steering(0)
    print("Emergency stop!")
```

#### リモート停止
```python
# キーボードからの停止
import threading

stop_flag = False

def listen_keyboard():
    global stop_flag
    input("Press Enter to stop...")
    stop_flag = True

threading.Thread(target=listen_keyboard, daemon=True).start()

# メインループ内
if stop_flag:
    motor.set_throttle(0)
    break
```

---

## 7. 評価指標

### 7.1 シミュレーター vs 実機

| 指標 | シミュレーター目標 | 実機目標 |
|---|---|---|
| 完走率 | 90%以上 | 70%以上 |
| 平均ラップタイム | - | ±20%以内 |
| 壁との最小距離 | >10cm | >20cm |
| 安定性（標準偏差） | 低い | 中程度 |

### 7.2 ログとモニタリング

```python
class PerformanceLogger:
    def __init__(self):
        self.episodes = []

    def log_episode(self, success, time, min_distance):
        self.episodes.append({
            'success': success,
            'time': time,
            'min_distance': min_distance,
        })

    def get_statistics(self):
        success_rate = np.mean([e['success'] for e in self.episodes])
        avg_time = np.mean([e['time'] for e in self.episodes if e['success']])
        avg_min_distance = np.mean([e['min_distance'] for e in self.episodes])

        return {
            'success_rate': success_rate,
            'avg_time': avg_time,
            'avg_min_distance': avg_min_distance,
        }
```

---

## まとめ

Sim-to-Real転移は段階的に進めることが重要です。Domain Randomizationを適切に実装し、実機でのキャリブレーションを丁寧に行うことで、シミュレーターで学習したポリシーを実機に効果的に転移できます。

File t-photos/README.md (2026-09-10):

## Equipo 

### Johelis Margarita Acosta
<p align="center">
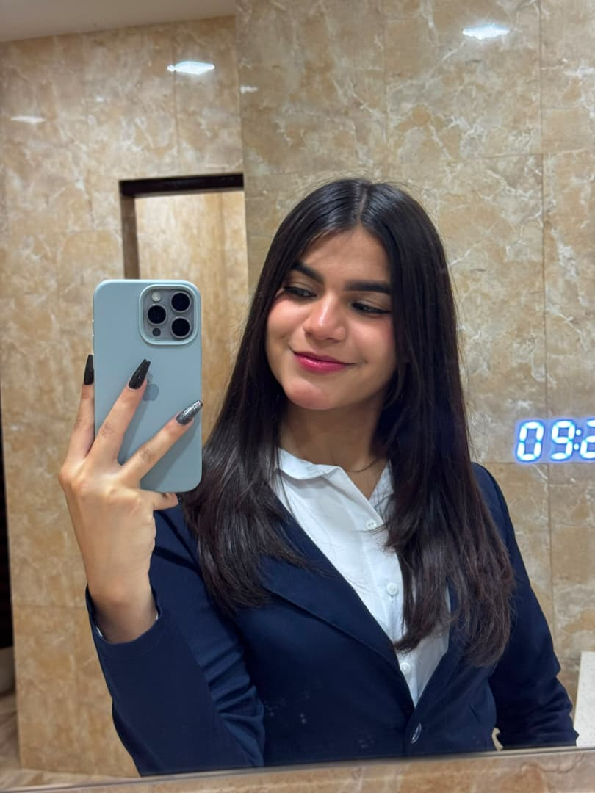
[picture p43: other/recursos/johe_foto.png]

</p>
<b>Edad:</b> 18 

<b>Institución educativa:</b> U.E.P.Arq. María Auxiliadora.

<b>Descripción:</b> ¡Hola! Soy Johelis, de Venezuela y esta es mi primera vez participando en la WRO. Cuento con experiencia previa en competencias de robots seguidores de línea y en proyectos de ingenio creativo. Además de la tecnología, me apasiona la fotografía, la música, el arte y Kuromi 💜.

---

### Miguel Alexander Mejías
<p align="center">
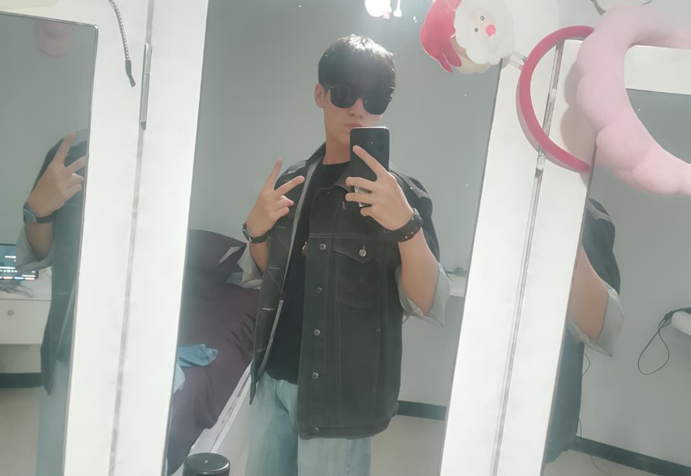
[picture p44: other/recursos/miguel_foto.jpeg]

</p>

<b>Edad:</b> 17

<b>Institución educativa:</b> U.E.P. José Gil Fortoul

<b>Descripción:</b> Soy Miguel Alexander y me apasiona la tecnología, los videojuegos y la programación. 
Uno de mis animes favoritos es Evangelion por ello estoy feliz de nuestro equipo el cuál quiere representar la parte buena y tecnológica de este anime. 
SAERY

---

### Guillermo Jesús Fernández
<p align="center">
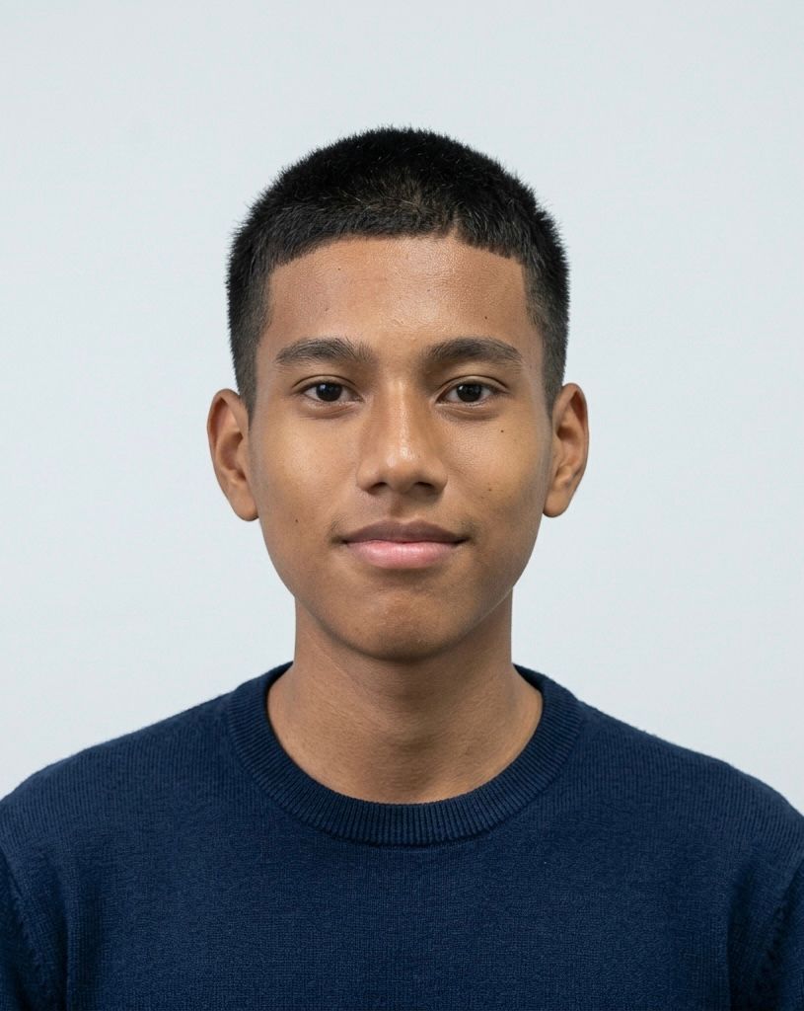
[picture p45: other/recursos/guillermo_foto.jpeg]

</p>
<b>edad:</b> 19

<b>Institución educativa:</b> U.N.C.Dr.Humberto Fernández Morán 

<b>Descripción:</b> Soy Guillermo Fernández, apasionado por el modelado 3D, la programación, los juegos de estrategia como el ajedrez y los videojuegos online. Me fascina la construcción y la innovación pensada para facilitar la vida diaria y ser parte de esa solución, por lo que me encanta aplicar esa vibra futurista a los prototipos que construimos en el taller. Orgulloso de formar parte de este proyecto.

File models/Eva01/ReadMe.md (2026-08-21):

En esta carpeta se encuentran todos los stls diseñados por nosotros y usados en algunas versiones del prototipo.

Algunos diseños fueron modificados o descartados para la fase final del prototipo.

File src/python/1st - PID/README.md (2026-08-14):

#**Este es el readme.** Estoy haciendo cambios.

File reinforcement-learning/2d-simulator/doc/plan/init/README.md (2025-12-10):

# 2Dシミュレーター実装計画 - 目次

このディレクトリには、ミニカー自動運転のための2D強化学習シミュレーターの詳細な実装計画が含まれています。

## ドキュメント一覧

### [00_overview.md](./00_overview.md) - 概要
- プロジェクトの目的と全体像
- 実装フェーズの概要
- 期待される成果物
- 成功指標

### [01_project_structure.md](./01_project_structure.md) - プロジェクト構造
- ディレクトリ構造の詳細
- 各モジュールの役割
- モジュール間の依存関係
- 命名規則とインターフェース設計原則

### [02_tech_stack.md](./02_tech_stack.md) - 技術スタック
- 使用するライブラリとその選定理由
- 完全なrequirements.txt
- 開発ツールの推奨事項
- ハードウェア要件

### [03_implementation_phases.md](./03_implementation_phases.md) - 実装フェーズ
- Phase 1: 基盤構築（2-3週間）
- Phase 2: 強化学習統合（2-3週間）
- Phase 3: 高度な機能（2-3週間）
- Phase 4: 検証と最適化（1-2週間）
- 各フェーズの詳細タスクとマイルストーン

### [04_component_design.md](./04_component_design.md) - コンポーネント設計
- シミュレーション環境の詳細設計
- 物理エンジンの実装
- 強化学習アルゴリズム（PPO）
- カリキュラム学習とDomain Randomization
- 実装例とコードスニペット

### [05_config_and_testing.md](./05_config_and_testing.md) - 設定とテスト
- 設定ファイルのサンプル（YAML形式）
- ユニットテスト戦略
- 統合テストとパフォーマンステスト
- CI/CD設定
- デバッグとトラブルシューティング

### [06_sim_to_real.md](./06_sim_to_real.md) - 実機転移
- Domain Randomization戦略
- 実機セットアップ手順
- モデルのデプロイ（PyTorch → ONNX）
- センサー・モーターキャリブレーション
- 段階的な転移プロセス
- トラブルシューティングと安全対策

### [07_getting_started.md](./07_getting_started.md) - 実装開始ガイド
- 開発環境のセットアップ手順
- Phase 1の具体的な実装順序
- 各タスクの実装例とテストコード
- 開発ワークフローとデバッグのヒント

---

## 推奨読み順

### 初めての方
1. **00_overview.md** - プロジェクト全体を理解
2. **01_project_structure.md** - 構造を把握
3. **07_getting_started.md** - 実装を開始

### 設計を理解したい方
1. **02_tech_stack.md** - 技術選定の背景
2. **04_component_design.md** - 詳細設計
3. **05_config_and_testing.md** - テスト戦略

### 実装を進める方
1. **03_implementation_phases.md** - タスクリスト
2. **07_getting_started.md** - 実装ガイド
3. **05_config_and_testing.md** - テスト実装

### 実機転移を考える方
1. **06_sim_to_real.md** - 転移戦略
2. **04_component_design.md** - ポリシーのデプロイ
3. **05_config_and_testing.md** - 実機テスト

---

## クイックリファレンス

### プロジェクト期間
- **総期間**: 8-10週間
- **Phase 1**: 2-3週間（基盤構築）
- **Phase 2**: 2-3週間（強化学習）
- **Phase 3**: 2-3週間（高度な機能）
- **Phase 4**: 1-2週間（検証）

### 主要技術
- **物理エンジン**: Box2D (PyBox2D)
- **強化学習**: PyTorch + PPO（スクラッチ実装）
- **環境**: Gymnasium
- **可視化**: Pygame, Matplotlib, TensorBoard

### 主要コンポーネント
1. **MinicarEnv** - Gym互換環境
2. **Vehicle** - 車両モデル
3. **LiDARSensor** - センサーシミュレーション
4. **Course** - コース定義
5. **PPO** - 強化学習アルゴリズム
6. **CurriculumManager** - カリキュラム学習
7. **PhysicsRandomizer** - Domain Randomization

---

## 重要なマイルストーン

### Phase 1完了条件
- [ ] 手動制御でコースを走行可能
- [ ] LiDARスキャンが正確に機能
- [ ] Pygameで可視化できる
- [ ] Gym互換インターフェースが動作

### Phase 2完了条件
- [ ] シンプルなコースで完走可能（成功率50%以上）
- [ ] PPOアルゴリズムが収束
- [ ] TensorBoardで学習過程を確認可能

### Phase 3完了条件
- [ ] カリキュラム学習が機能
- [ ] Domain Randomizationで学習が収束
- [ ] ショートカットを活用して走行

### Phase 4完了条件
- [ ] 評価指標が目標値を達成
- [ ] 実機デプロイ用コードが動作
- [ ] ドキュメントが整備されている

---

## 連絡先・質問

実装中に疑問が生じた場合:
1. 関連するドキュメントを再確認
2. テストコードを参考に実装
3. デバッグセクションを確認

---

## バージョン

- **作成日**: 2025-12-09
- **バージョン**: 1.0.0
- **最終更新**: 2025-12-09

---

## ライセンス

このプロジェクトは社内プロジェクトです。

---

## 次のアクション

1. **開発環境のセットアップ**: [07_getting_started.md](./07_getting_started.md)を参照
2. **Phase 1の開始**: [03_implementation_phases.md](./03_implementation_phases.md)のWeek 1タスクを確認
3. **最初のコミット**: ディレクトリ構造とrequirements.txtを作成

それでは、実装を開始しましょう！

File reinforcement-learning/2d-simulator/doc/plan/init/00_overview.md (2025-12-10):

# 2Dシミュレーター実装計画 概要

## 目的

ミニカー自動運転のための2D強化学習シミュレーターを構築する。

## 主要な設計方針

1. **軽量性**: 2D物理エンジンを使用し、大量の試行回数を確保
2. **実機転移性**: Domain Randomizationにより実機への転移を促進
3. **段階的学習**: カリキュラム学習により効率的な学習を実現
4. **モジュール性**: 各コンポーネントを独立させ、拡張性を確保

## 実装範囲

### Phase 1: 基盤構築（2-3週間）
- 2Dシミュレーター環境の構築
- 基本的な物理演算の実装
- LiDARセンサーシミュレーション
- Gym互換インターフェース

### Phase 2: 強化学習統合（2-3週間）
- PPOアルゴリズムの実装
- 報酬関数の実装と調整
- 学習ループの構築
- TensorBoard統合

### Phase 3: 高度な機能（2-3週間）
- カリキュラム学習の実装
- Domain Randomizationの実装
- チェックポイントシステム
- 複数コースの実装

### Phase 4: 検証と最適化（1-2週間）
- 学習の安定性確認
- ハイパーパラメータチューニング
- 可視化ツールの改善
- ドキュメント整備

## 期待される成果物

1. Gym互換の2Dシミュレーター環境
2. PPOベースの学習エージェント
3. コース設計ツール
4. 学習済みモデル
5. 実機転移用のデプロイツール
6. 包括的なドキュメント

## 成功指標

- シミュレーターで安定して完走可能（成功率90%以上）
- ショートカットの発見と活用
- 学習時間: 各コースで2-4時間以内
- シミュレーション速度: リアルタイムの10倍以上

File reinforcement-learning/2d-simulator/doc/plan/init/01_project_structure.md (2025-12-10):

# プロジェクト構造設計

## ディレクトリ構造

```
2d-simulator/
├── README.md
├── requirements.txt
├── setup.py
├── .gitignore
│
├── doc/
│   ├── plan/              # 実装計画
│   ├── design/            # 設計ドキュメント
│   └── api/               # APIドキュメント
│
├── src/
│   ├── __init__.py
│   │
│   ├── env/               # シミュレーション環境
│   │   ├── __init__.py
│   │   ├── minicar_env.py          # メインの環境クラス (Gym互換)
│   │   ├── world.py                # 物理世界の管理
│   │   ├── vehicle.py              # 車両モデル
│   │   ├── sensors.py              # センサーシミュレーション
│   │   ├── course.py               # コース定義とロード
│   │   └── renderer.py             # 可視化レンダラー
│   │
│   ├── physics/           # 物理演算
│   │   ├── __init__.py
│   │   ├── box2d_wrapper.py        # Box2Dラッパー
│   │   └── collision_handler.py    # 衝突検出
│   │
│   ├── rl/                # 強化学習関連
│   │   ├── __init__.py
│   │   ├── ppo.py                  # PPOアルゴリズム実装
│   │   ├── policy.py               # ポリシーネットワーク
│   │   ├── value.py                # 価値関数ネットワーク
│   │   ├── buffer.py               # 経験バッファ
│   │   └── trainer.py              # 学習ループ
│   │
│   ├── curriculum/        # カリキュラム学習
│   │   ├── __init__.py
│   │   ├── curriculum_manager.py   # 難易度調整
│   │   └── reward_shaping.py       # 報酬の形成
│   │
│   ├── domain_randomization/  # Domain Randomization
│   │   ├── __init__.py
│   │   ├── physics_randomizer.py   # 物理パラメータのランダム化
│   │   └── sensor_noise.py         # センサーノイズ
│   │
│   ├── utils/             # ユーティリティ
│   │   ├── __init__.py
│   │   ├── config.py               # 設定管理
│   │   ├── logger.py               # ロギング
│   │   └── visualization.py        # データ可視化
│   │
│   └── deploy/            # 実機デプロイ用
│       ├── __init__.py
│       ├── model_converter.py      # モデル変換
│       └── rpi_inference.py        # Raspberry Pi推論
│
├── courses/               # コースデータ
│   ├── easy/
│   │   └── simple_oval.json
│   ├── medium/
│   │   └── shortcut_1.json
│   └── hard/
│       └── narrow_passage.json
│
├── configs/               # 設定ファイル
│   ├── env_config.yaml            # 環境設定
│   ├── training_config.yaml       # 学習設定
│   └── model_config.yaml          # モデル設定
│
├── scripts/               # 実行スクリプト
│   ├── train.py                   # 学習実行
│   ├── evaluate.py                # 評価
│   ├── visualize.py               # 可視化
│   └── create_course.py           # コース作成ツール
│
├── tests/                 # テストコード
│   ├── test_env.py
│   ├── test_vehicle.py
│   ├── test_sensors.py
│   └── test_ppo.py
│
├── notebooks/             # Jupyter Notebooks
│   ├── explore_env.ipynb
│   ├── analyze_training.ipynb
│   └── visualize_policy.ipynb
│
├── models/                # 学習済みモデル
│   ├── checkpoints/
│   └── best/
│
└── logs/                  # ログとTensorBoard
    ├── tensorboard/
    └── training/
```

## 各ディレクトリの役割

### src/env/
シミュレーション環境の中核。Gym互換インターフェースを実装し、物理演算、センサー、レンダリングを統合する。

### src/physics/
Box2Dをラップし、車両の動力学と衝突検出を実装。物理パラメータの調整が容易な設計。

### src/rl/
PPOアルゴリズムの実装。PyTorchを使用し、学習ループ、ポリシー、価値関数を含む。

### src/curriculum/
段階的な学習を管理。コースの難易度調整と報酬の形成を担当。

### src/domain_randomization/
Sim-to-Real対策。物理パラメータとセンサーノイズのランダム化を実装。

### courses/
コース定義をJSONで保存。壁の座標、チェックポイント、スタート/ゴール位置を含む。

### configs/
YAML形式の設定ファイル。ハイパーパラメータを外部から変更可能。

### scripts/
学習、評価、可視化の実行スクリプト。コマンドライン引数で柔軟に実行可能。

### tests/
ユニットテストと統合テスト。CI/CDパイプラインで自動実行。

## モジュール間の依存関係

```
scripts/
  ↓
src/rl/ → src/env/ → src/physics/
  ↓          ↓
src/curriculum/  src/domain_randomization/
  ↓          ↓
src/utils/
```

## 命名規則

- **クラス名**: PascalCase (例: `MinicarEnv`, `PPOTrainer`)
- **関数/メソッド名**: snake_case (例: `step()`, `get_observation()`)
- **定数**: UPPER_SNAKE_CASE (例: `MAX_STEPS`, `LIDAR_RANGE`)
- **プライベートメソッド**: `_`プレフィックス (例: `_compute_reward()`)
- **ファイル名**: snake_case (例: `minicar_env.py`)

## インターフェース設計原則

1. **Gym互換性**: 環境は`gym.Env`を継承し、標準的な`reset()`, `step()`, `render()`を実装
2. **設定の外部化**: ハードコーディングを避け、YAMLファイルで設定管理
3. **疎結合**: 各モジュールは独立して動作可能
4. **テスタビリティ**: 各コンポーネントは単体テストが可能
5. **拡張性**: 新しいセンサーやアルゴリズムを容易に追加可能

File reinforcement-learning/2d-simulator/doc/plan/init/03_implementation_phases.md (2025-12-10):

# 実装フェーズとマイルストーン

## Phase 1: 基盤構築（2-3週間）

### 目標
2Dシミュレーター環境の基礎を構築し、手動制御で動作確認できる状態にする。

### タスク一覧

#### Week 1: 環境セットアップと基本構造
1. **プロジェクト初期化** (1日)
   - ディレクトリ構造の作成
   - `requirements.txt`の作成
   - `.gitignore`の設定
   - 初期テストの作成

2. **Box2D物理エンジンの統合** (2-3日)
   - `src/physics/box2d_wrapper.py`の実装
   - 車両の基本物理モデル作成
   - 摩擦、慣性、モーター力の実装
   - 単体テストの作成

3. **車両モデルの実装** (2-3日)
   - `src/env/vehicle.py`の実装
   - ステアリング、スロットル制御
   - 車両パラメータ（質量、サイズ、最大速度）
   - 車両状態の取得（位置、速度、角速度）

#### Week 2: センサーとコース
4. **LiDARセンサーシミュレーション** (3-4日)
   - `src/env/sensors.py`の実装
   - レイキャスティングによる距離測定
   - 5度刻み、72方向のスキャン
   - センサーノイズの基本実装
   - 可視化機能

5. **コースシステム** (2-3日)
   - `src/env/course.py`の実装
   - JSON形式のコース定義
   - 壁の定義（ポリゴン）
   - スタート/ゴール位置
   - シンプルな楕円コースの作成

6. **Pygameレンダラー** (1-2日)
   - `src/env/renderer.py`の実装
   - 車両、壁、LiDARスキャンの描画
   - リアルタイム表示
   - デバッグ情報の表示

#### Week 2-3: Gym環境統合
7. **Gym互換環境** (2-3日)
   - `src/env/minicar_env.py`の実装
   - `reset()`, `step()`, `render()`メソッド
   - 行動空間・観測空間の定義
   - 基本的な報酬関数

8. **手動制御テスト** (1日)
   - キーボード入力での車両制御
   - 動作確認スクリプト作成
   - パラメータチューニング

### マイルストーン: Phase 1完了条件
- [ ] 手動制御でコースを走行可能
- [ ] LiDARスキャンが正確に機能
- [ ] Pygameで可視化できる
- [ ] Gym互換インターフェースが動作
- [ ] 基本的なテストがパス

---

## Phase 2: 強化学習統合（2-3週間）

### 目標
PPOアルゴリズムを実装し、基本的な走行を学習できる状態にする。

### タスク一覧

#### Week 3: ニューラルネットワーク
1. **ポリシーネットワーク** (2-3日)
   - `src/rl/policy.py`の実装
   - 観測→行動のマッピング
   - 連続行動空間（Gaussian policy）
   - 正規化レイヤーの追加

2. **価値関数ネットワーク** (1-2日)
   - `src/rl/value.py`の実装
   - 状態価値の推定
   - ポリシーと共通のエンコーダ（オプション）

3. **経験バッファ** (1日)
   - `src/rl/buffer.py`の実装
   - 軌跡の保存
   - GAE（Generalized Advantage Estimation）
   - バッチサンプリング

#### Week 4: PPOアルゴリズム
4. **PPOコア実装** (3-4日)
   - `src/rl/ppo.py`の実装
   - クリッピング損失関数
   - エントロピーボーナス
   - 価値関数損失
   - 勾配更新ロジック

5. **学習ループ** (2-3日)
   - `src/rl/trainer.py`の実装
   - エピソード収集
   - PPO更新の実行
   - チェックポイント保存
   - 学習の安定化（報酬正規化等）

6. **TensorBoard統合** (1日)
   - `src/utils/logger.py`の実装
   - 報酬、損失のロギング
   - ネットワークパラメータの可視化
   - エピソード長の追跡

#### Week 5: 初期学習と調整
7. **基本報酬関数の実装** (2日)
   - 前進報酬（速度ベース）
   - 壁衝突ペナルティ
   - 時間ペナルティ
   - ゴール報酬

8. **ハイパーパラメータ調整** (2-3日)
   - 学習率、バッチサイズ等の調整
   - 報酬スケールの調整
   - エピソード長の最適化

9. **学習スクリプト** (1日)
   - `scripts/train.py`の作成
   - コマンドライン引数の実装
   - 設定ファイルの読み込み

### マイルストーン: Phase 2完了条件
- [ ] シンプルなコースで完走可能（成功率50%以上）
- [ ] PPOアルゴリズムが収束
- [ ] TensorBoardで学習過程を確認可能
- [ ] 学習時間が1-2時間以内

---

## Phase 3: 高度な機能（2-3週間）

### 目標
カリキュラム学習、Domain Randomization、ショートカット学習を実装。

### タスク一覧

#### Week 6: カリキュラム学習
1. **カリキュラムマネージャー** (2-3日)
   - `src/curriculum/curriculum_manager.py`
   - 難易度レベルの定義
   - 自動難易度調整
   - 複数コースの管理

2. **報酬シェーピング** (2日)
   - `src/curriculum/reward_shaping.py`
   - 段階的な報酬調整
   - チェックポイントシステムの実装
   - 壁接近ペナルティの動的調整

3. **複数コースの作成** (1-2日)
   - 易しいコース（wide_oval.json）
   - 中難易度（narrow_oval.json）
   - ショートカット付き（shortcut_1.json）

#### Week 7: Domain Randomization
4. **物理パラメータのランダム化** (2-3日)
   - `src/domain_randomization/physics_randomizer.py`
   - 摩擦係数のランダム化
   - 質量・慣性のランダム化
   - モーター応答遅延のランダム化

5. **センサーノイズ** (1-2日)
   - `src/domain_randomization/sensor_noise.py`
   - LiDARノイズの追加
   - IMUノイズのシミュレーション

6. **統合と学習** (2-3日)
   - Domain Randomizationを有効にした学習
   - パラメータ範囲の調整
   - 学習の安定性確認

#### Week 8: ショートカット学習
7. **チェックポイントシステム** (2-3日)
   - コース進行度の正確な計算
   - 複数ルート対応
   - ショートカット検出

8. **ショートカット報酬** (1-2日)
   - ショートカット通過ボーナス
   - リスク・リターンのバランス調整

9. **複雑なコースでの学習** (2-3日)
   - ショートカット付きコースでの学習
   - 報酬パラメータの微調整
   - エージェントの行動分析

### マイルストーン: Phase 3完了条件
- [ ] カリキュラム学習が機能（易→難への自動遷移）
- [ ] Domain Randomizationで学習が収束
- [ ] ショートカットを活用して走行
- [ ] 複数コースで高い成功率（80%以上）

---

## Phase 4: 検証と最適化（1-2週間）

### 目標
システム全体の安定性を確認し、実機転移の準備を整える。

### タスク一覧

#### Week 9: 評価と可視化
1. **評価スクリプト** (1-2日)
   - `scripts/evaluate.py`の作成
   - 複数エピソードの統計情報
   - 成功率、平均ラップタイムの計算
   - ベストモデルの選定

2. **可視化ツール** (1-2日)
   - `scripts/visualize.py`の作成
   - 学習済みポリシーの実行動画
   - 軌跡の記録と可視化
   - LiDARスキャンのアニメーション

3. **分析ノートブック** (1-2日)
   - `notebooks/analyze_training.ipynb`
   - 学習曲線の分析
   - 報酬要素の貢献度分析
   - ハイパーパラメータの影響調査

#### Week 9-10: 実機転移準備
4. **モデル変換** (1-2日)
   - `src/deploy/model_converter.py`
   - PyTorch → ONNX変換
   - 推論速度の最適化
   - モデルサイズの削減

5. **Raspberry Pi推論** (2-3日)
   - `src/deploy/rpi_inference.py`
   - ONNX Runtimeでの推論
   - 観測データの前処理
   - 制御コマンドの出力

6. **シミュレーション vs 実機ギャップ分析** (1-2日)
   - センサー精度の比較
   - 応答遅延の測定
   - 必要な補正の特定

#### Week 10: ドキュメントと最終調整
7. **APIドキュメント** (1日)
   - docstringの追加
   - Sphinx設定（オプション）
   - 使用例の作成

8. **ユーザーガイド** (1日)
   - セットアップ手順
   - 学習の実行方法
   - トラブルシューティング

9. **最終テストとバグ修正** (2-3日)
   - 統合テストの実行
   - エッジケースの確認
   - パフォーマンス最適化

### マイルストーン: Phase 4完了条件
- [ ] 評価指標が目標値を達成
- [ ] 実機デプロイ用コードが動作
- [ ] ドキュメントが整備されている
- [ ] 全テストがパス
- [ ] 学習済みモデルが保存されている

---

## 全体スケジュール

```
Week 1-2:  Phase 1 - 基盤構築
Week 3-5:  Phase 2 - 強化学習統合
Week 6-8:  Phase 3 - 高度な機能
Week 9-10: Phase 4 - 検証と最適化
```

**総期間: 8-10週間**

## リスクとバッファ

### 想定リスク
1. **PPOの学習が不安定**: 報酬設計の見直し、ハイパーパラメータ調整（+1週間）
2. **物理パラメータの調整難航**: 実機データを先に取得（+1週間）
3. **ショートカット学習が困難**: 報酬関数の抜本的見直し（+2週間）

### バッファ期間
- 各フェーズに1週間の予備期間を設定
- 合計で2-3週間のバッファ

## 次のステップ

Phase 1完了後、以下を実施：
1. 動作デモ動画の作成
2. 初期結果の共有
3. Phase 2への移行判断

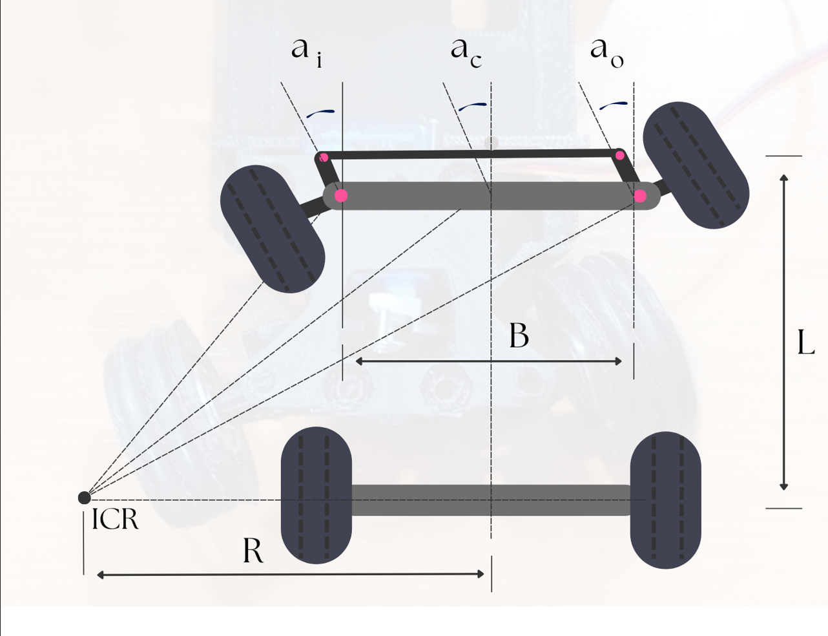
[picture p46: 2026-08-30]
ackerman.png

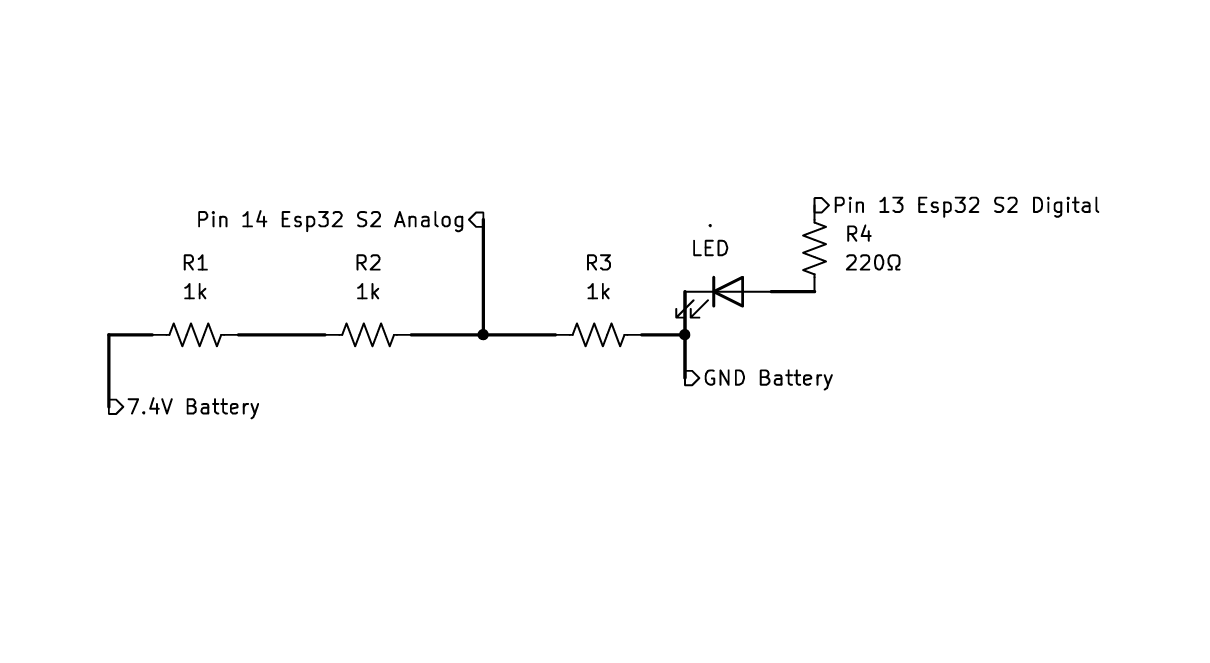
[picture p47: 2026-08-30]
diagrama divisor de voltaje.png

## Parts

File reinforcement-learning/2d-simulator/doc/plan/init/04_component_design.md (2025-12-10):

# コンポーネント詳細設計

## 1. シミュレーション環境 (`src/env/`)

### 1.1 MinicarEnv (minicar_env.py)

Gym互換の環境クラス。すべてのコンポーネントを統合。

#### クラス定義
```python
class MinicarEnv(gym.Env):
    metadata = {'render_modes': ['human', 'rgb_array'], 'render_fps': 30}

    def __init__(self, config: dict):
        """
        Args:
            config: 環境設定（YAMLから読み込み）
        """

    def reset(self, seed=None, options=None) -> Tuple[np.ndarray, dict]:
        """環境をリセット"""

    def step(self, action: np.ndarray) -> Tuple[np.ndarray, float, bool, bool, dict]:
        """
        Args:
            action: [steering, throttle] (-1~1, 0~1)
        Returns:
            observation, reward, terminated, truncated, info
        """

    def render(self):
        """Pygameで描画"""

    def close(self):
        """リソースの解放"""
```

#### 観測空間
```python
observation_space = gym.spaces.Dict({
    'lidar': gym.spaces.Box(low=0, high=10, shape=(72,), dtype=np.float32),
    'velocity': gym.spaces.Box(low=-10, high=10, shape=(2,), dtype=np.float32),
    'angular_velocity': gym.spaces.Box(low=-5, high=5, shape=(1,), dtype=np.float32),
    'last_action': gym.spaces.Box(low=-1, high=1, shape=(2,), dtype=np.float32),
})
```

**フラット化した観測（PPO用）:**
```python
# 合計77次元
obs_flat = np.concatenate([
    lidar_scan,           # 72
    velocity,             # 2 (vx, vy)
    angular_velocity,     # 1
    last_action,          # 2 (steering, throttle)
])
```

#### 行動空間
```python
action_space = gym.spaces.Box(
    low=np.array([-1.0, 0.0]),   # [min_steering, min_throttle]
    high=np.array([1.0, 1.0]),   # [max_steering, max_throttle]
    dtype=np.float32
)
```

#### 報酬関数
```python
def _compute_reward(self) -> float:
    reward = 0.0

    # 1. 前進報酬（コース進行）
    progress = self._get_course_progress()
    reward += progress * 1.0

    # 2. 速度報酬
    speed = np.linalg.norm(self.vehicle.velocity)
    reward += speed * 0.1

    # 3. 時間ペナルティ
    reward -= 0.01

    # 4. 壁接近ペナルティ
    min_distance = np.min(self.lidar_scan)
    if min_distance < 0.3:
        reward -= (0.3 - min_distance) * 10

    # 5. 壁衝突（終了）
    if self._check_collision():
        reward -= 100

    # 6. ゴール到達
    if self._check_goal():
        reward += 500

    return reward
```

---

### 1.2 Vehicle (vehicle.py)

車両の物理モデルと制御。

#### クラス定義
```python
class Vehicle:
    def __init__(self, world: b2World, start_pos: Tuple[float, float], start_angle: float):
        self.body = None  # Box2Dのbody
        self.width = 0.2  # m
        self.length = 0.4  # m
        self.mass = 1.0   # kg

        self.max_steering_angle = 0.5  # rad
        self.max_motor_force = 20.0    # N

    def apply_control(self, steering: float, throttle: float):
        """制御入力を適用"""

    def get_state(self) -> dict:
        """現在の状態を取得"""
        return {
            'position': self.body.position,
            'angle': self.body.angle,
            'velocity': self.body.linearVelocity,
            'angular_velocity': self.body.angularVelocity,
        }
```

#### 制御モデル（Ackermann steering）
```python
def apply_control(self, steering: float, throttle: float):
    # ステアリング角度
    steer_angle = steering * self.max_steering_angle

    # 前後の車輪位置
    rear_wheel_pos = self.body.position
    front_wheel_pos = rear_wheel_pos + self.length * Vec2(cos(angle), sin(angle))

    # モーター力
    motor_force = throttle * self.max_motor_force
    force_direction = Vec2(cos(angle + steer_angle), sin(angle + steer_angle))
    self.body.ApplyForce(motor_force * force_direction, front_wheel_pos, True)

    # 横滑り抑制（簡易的な摩擦モデル）
    lateral_velocity = self._get_lateral_velocity()
    impulse = -lateral_velocity * self.mass * 0.5
    self.body.ApplyLinearImpulse(impulse, self.body.position, True)
```

---

### 1.3 LiDAR Sensor (sensors.py)

レイキャスティングによる距離測定。

#### クラス定義
```python
class LiDARSensor:
    def __init__(self, world: b2World, num_rays: int = 72, max_range: float = 10.0):
        self.world = world
        self.num_rays = num_rays
        self.max_range = max_range
        self.angle_increment = 2 * np.pi / num_rays

    def scan(self, position: Vec2, orientation: float) -> np.ndarray:
        """
        Returns:
            distances: (num_rays,) 各方向の距離
        """
        distances = np.zeros(self.num_rays)

        for i in range(self.num_rays):
            angle = orientation + i * self.angle_increment
            direction = Vec2(np.cos(angle), np.sin(angle))

            # レイキャスト
            hit_point, hit_distance = self._raycast(position, direction)
            distances[i] = hit_distance if hit_distance else self.max_range

        return distances

    def _raycast(self, start: Vec2, direction: Vec2) -> Tuple[Vec2, float]:
        """Box2Dのレイキャスト"""
        # RayCastCallback実装
        ...
```

#### ノイズモデル
```python
def add_noise(self, distances: np.ndarray, noise_level: float = 0.01) -> np.ndarray:
    """
    ガウシアンノイズを追加
    """
    noise = np.random.normal(0, noise_level * self.max_range, distances.shape)
    return np.clip(distances + noise, 0, self.max_range)
```

---

### 1.4 Course (course.py)

コースの定義とロード。

#### JSON形式
```json
{
  "name": "simple_oval",
  "start_position": [1.0, 1.0],
  "start_angle": 0.0,
  "goal_position": [1.0, 1.0],
  "goal_radius": 0.5,
  "walls": [
    {
      "type": "polygon",
      "vertices": [[0, 0], [10, 0], [10, 8], [0, 8]]
    }
  ],
  "checkpoints": [
    {"position": [5.0, 1.0], "radius": 1.0},
    {"position": [9.0, 4.0], "radius": 1.0}
  ]
}
```

#### クラス定義
```python
class Course:
    def __init__(self, course_file: str):
        self.data = self._load_json(course_file)
        self.walls = []

    def create_walls(self, world: b2World):
        """Box2Dの静的bodyとして壁を生成"""
        for wall_data in self.data['walls']:
            vertices = wall_data['vertices']
            # staticBodyとしてポリゴン生成
            ...

    def get_start_pose(self) -> Tuple[Vec2, float]:
        """スタート位置と角度"""

    def check_checkpoint(self, position: Vec2) -> int:
        """チェックポイント通過判定"""
```

---

## 2. 物理エンジン (`src/physics/`)

### 2.1 Box2D Wrapper (box2d_wrapper.py)

Box2Dの初期化と管理。

```python
class PhysicsWorld:
    def __init__(self, gravity: Vec2 = (0, 0)):
        self.world = b2World(gravity=gravity, doSleep=True)
        self.time_step = 1.0 / 60.0
        self.vel_iters = 8
        self.pos_iters = 3

    def step(self):
        """物理シミュレーションを1ステップ進める"""
        self.world.Step(self.time_step, self.vel_iters, self.pos_iters)

    def add_static_polygon(self, vertices: List[Vec2]) -> b2Body:
        """静的なポリゴン（壁）を追加"""
        body = self.world.CreateStaticBody(
            shapes=b2PolygonShape(vertices=vertices)
        )
        return body
```

---

## 3. 強化学習 (`src/rl/`)

### 3.1 Policy Network (policy.py)

観測から行動への写像。

```python
class GaussianPolicy(nn.Module):
    def __init__(self, obs_dim: int, action_dim: int, hidden_sizes: List[int] = [256, 256]):
        super().__init__()

        # 共有エンコーダ
        self.encoder = nn.Sequential(
            nn.Linear(obs_dim, hidden_sizes[0]),
            nn.ReLU(),
            nn.Linear(hidden_sizes[0], hidden_sizes[1]),
            nn.ReLU(),
        )

        # 平均と対数標準偏差
        self.mean_head = nn.Linear(hidden_sizes[1], action_dim)
        self.log_std_head = nn.Linear(hidden_sizes[1], action_dim)

    def forward(self, obs: torch.Tensor) -> Tuple[torch.Tensor, torch.Tensor]:
        """
        Returns:
            mean, log_std
        """
        features = self.encoder(obs)
        mean = self.mean_head(features)
        log_std = self.log_std_head(features)
        log_std = torch.clamp(log_std, -20, 2)  # 安定化
        return mean, log_std

    def sample(self, obs: torch.Tensor) -> Tuple[torch.Tensor, torch.Tensor]:
        """
        Returns:
            action, log_prob
        """
        mean, log_std = self.forward(obs)
        std = torch.exp(log_std)
        dist = Normal(mean, std)
        action = dist.sample()
        log_prob = dist.log_prob(action).sum(dim=-1)
        return action, log_prob
```

### 3.2 Value Network (value.py)

状態価値関数。

```python
class ValueNetwork(nn.Module):
    def __init__(self, obs_dim: int, hidden_sizes: List[int] = [256, 256]):
        super().__init__()
        self.network = nn.Sequential(
            nn.Linear(obs_dim, hidden_sizes[0]),
            nn.ReLU(),
            nn.Linear(hidden_sizes[0], hidden_sizes[1]),
            nn.ReLU(),
            nn.Linear(hidden_sizes[1], 1),
        )

    def forward(self, obs: torch.Tensor) -> torch.Tensor:
        return self.network(obs).squeeze(-1)
```

### 3.3 PPO Algorithm (ppo.py)

```python
class PPO:
    def __init__(self, policy: GaussianPolicy, value: ValueNetwork, config: dict):
        self.policy = policy
        self.value = value

        self.lr = config['learning_rate']
        self.clip_ratio = config['clip_ratio']
        self.entropy_coef = config['entropy_coef']
        self.value_coef = config['value_coef']

        self.optimizer = Adam([
            {'params': policy.parameters()},
            {'params': value.parameters()},
        ], lr=self.lr)

    def update(self, buffer: RolloutBuffer) -> dict:
        """
        PPO更新を実行

        Returns:
            統計情報（損失等）
        """
        for epoch in range(self.num_epochs):
            for batch in buffer.get_batches(self.batch_size):
                # 現在のポリシーでログ確率を計算
                _, new_log_probs = self.policy.sample(batch.obs)

                # Advantage
                advantages = batch.returns - batch.values
                advantages = (advantages - advantages.mean()) / (advantages.std() + 1e-8)

                # Policy loss (PPO clip)
                ratio = torch.exp(new_log_probs - batch.log_probs)
                surr1 = ratio * advantages
                surr2 = torch.clamp(ratio, 1 - self.clip_ratio, 1 + self.clip_ratio) * advantages
                policy_loss = -torch.min(surr1, surr2).mean()

                # Value loss
                values_pred = self.value(batch.obs)
                value_loss = F.mse_loss(values_pred, batch.returns)

                # Entropy bonus
                entropy = ... # 計算

                # Total loss
                loss = policy_loss + self.value_coef * value_loss - self.entropy_coef * entropy

                # 更新
                self.optimizer.zero_grad()
                loss.backward()
                nn.utils.clip_grad_norm_(self.policy.parameters(), max_norm=0.5)
                self.optimizer.step()
```

### 3.4 Rollout Buffer (buffer.py)

```python
class RolloutBuffer:
    def __init__(self, capacity: int, obs_dim: int, action_dim: int, gamma: float, gae_lambda: float):
        self.observations = np.zeros((capacity, obs_dim))
        self.actions = np.zeros((capacity, action_dim))
        self.rewards = np.zeros(capacity)
        self.values = np.zeros(capacity)
        self.log_probs = np.zeros(capacity)
        self.dones = np.zeros(capacity)

        self.gamma = gamma
        self.gae_lambda = gae_lambda

    def add(self, obs, action, reward, value, log_prob, done):
        """経験を追加"""

    def compute_returns_and_advantages(self, last_value: float):
        """GAEを使ってリターンとAdvantageを計算"""
        advantages = np.zeros_like(self.rewards)
        last_gae = 0

        for t in reversed(range(len(self.rewards))):
            if t == len(self.rewards) - 1:
                next_value = last_value
            else:
                next_value = self.values[t + 1]

            delta = self.rewards[t] + self.gamma * next_value * (1 - self.dones[t]) - self.values[t]
            advantages[t] = last_gae = delta + self.gamma * self.gae_lambda * (1 - self.dones[t]) * last_gae

        returns = advantages + self.values
        return returns, advantages
```

---

## 4. カリキュラム学習 (`src/curriculum/`)

### 4.1 Curriculum Manager

```python
class CurriculumManager:
    def __init__(self, courses: List[str], success_threshold: float = 0.8):
        self.courses = courses  # 易→難の順
        self.current_level = 0
        self.success_threshold = success_threshold
        self.recent_success_rate = deque(maxlen=100)

    def update(self, success: bool):
        """エピソード結果を記録"""
        self.recent_success_rate.append(success)

    def should_advance(self) -> bool:
        """次のレベルに進むべきか判定"""
        if len(self.recent_success_rate) < 50:
            return False
        success_rate = np.mean(self.recent_success_rate)
        return success_rate >= self.success_threshold

    def advance_level(self):
        """次のレベルに進む"""
        if self.current_level < len(self.courses) - 1:
            self.current_level += 1
            self.recent_success_rate.clear()
```

---

## 5. Domain Randomization (`src/domain_randomization/`)

### 5.1 Physics Randomizer

```python
class PhysicsRandomizer:
    def __init__(self, config: dict):
        self.friction_range = config.get('friction_range', (0.5, 1.5))
        self.mass_range = config.get('mass_range', (0.8, 1.2))
        self.motor_delay_range = config.get('motor_delay_range', (0, 0.05))

    def randomize(self, vehicle: Vehicle):
        """車両パラメータをランダム化"""
        vehicle.friction = np.random.uniform(*self.friction_range)
        vehicle.mass = np.random.uniform(*self.mass_range)
        vehicle.motor_delay = np.random.uniform(*self.motor_delay_range)
```

---

## 6. ユーティリティ (`src/utils/`)

### 6.1 Config Manager

```python
class ConfigManager:
    def __init__(self, config_path: str):
        with open(config_path) as f:
            self.config = yaml.safe_load(f)

    def get(self, key: str, default=None):
        return self.config.get(key, default)
```

### 6.2 Logger

```python
class TensorBoardLogger:
    def __init__(self, log_dir: str):
        self.writer = SummaryWriter(log_dir)

    def log_scalar(self, tag: str, value: float, step: int):
        self.writer.add_scalar(tag, value, step)

    def log_histogram(self, tag: str, values: np.ndarray, step: int):
        self.writer.add_histogram(tag, values, step)
```

---

## 7. 実行スクリプト (`scripts/`)

### 7.1 Training Script

```python
# scripts/train.py
def main(config_path: str):
    # 設定ロード
    config = ConfigManager(config_path)

    # 環境作成
    env = MinicarEnv(config.get('env'))

    # エージェント作成
    policy = GaussianPolicy(...)
    value = ValueNetwork(...)
    ppo = PPO(policy, value, config.get('ppo'))

    # カリキュラムマネージャー
    curriculum = CurriculumManager(config.get('courses'))

    # 学習ループ
    for episode in range(num_episodes):
        obs, _ = env.reset()
        done = False

        while not done:
            action, log_prob = policy.sample(obs)
            next_obs, reward, terminated, truncated, info = env.step(action)
            # バッファに保存
            ...

        # PPO更新
        if episode % update_interval == 0:
            ppo.update(buffer)
```

---

## まとめ

各コンポーネントは独立して開発・テスト可能な設計になっています。Phase 1では基盤となる`env`, `physics`モジュールを実装し、Phase 2で`rl`モジュールを統合します。

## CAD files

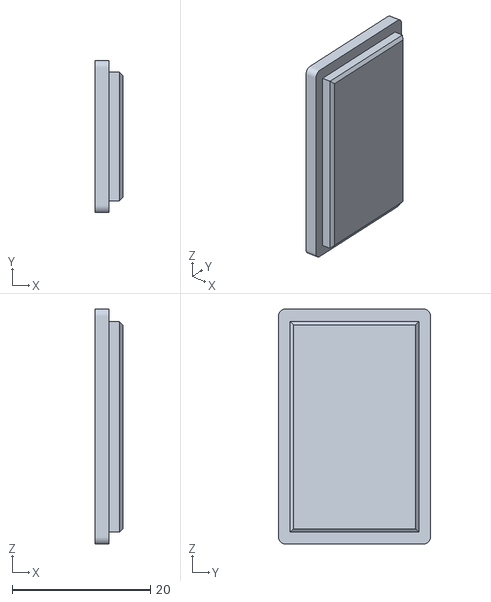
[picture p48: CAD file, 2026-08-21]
models/Eva01/Fuente de poder - tapa.stl
4.00 x 22.0 x 34.0

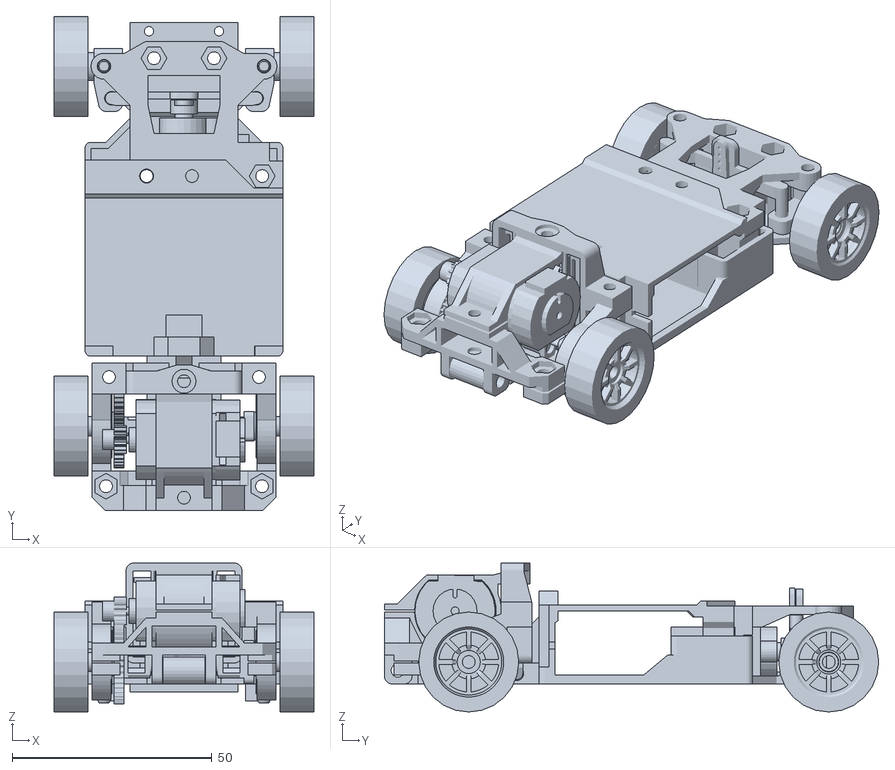
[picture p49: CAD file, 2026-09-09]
models/zcar/zcar.stl
65.0 x 123.6 x 37.2

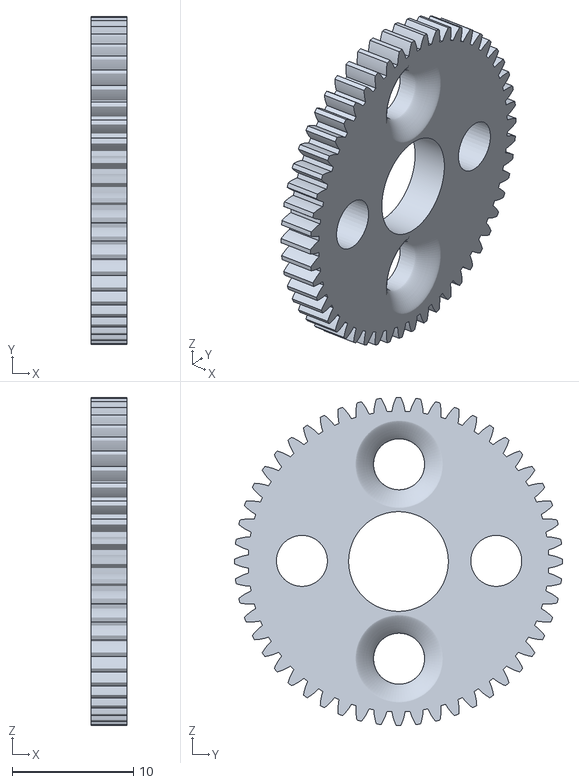
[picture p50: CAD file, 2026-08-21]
models/Eva01/Spur_M0.5_Pa20_Z52.stl
3.00 x 27.0 x 27.0

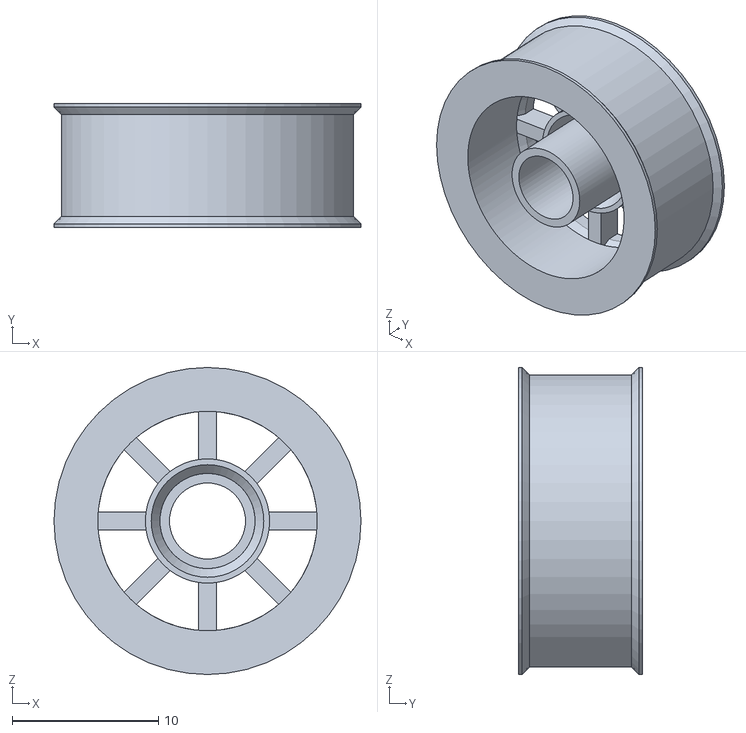
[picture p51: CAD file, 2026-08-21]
models/Eva01/rear-tire.stl
21.0 x 8.50 x 21.0

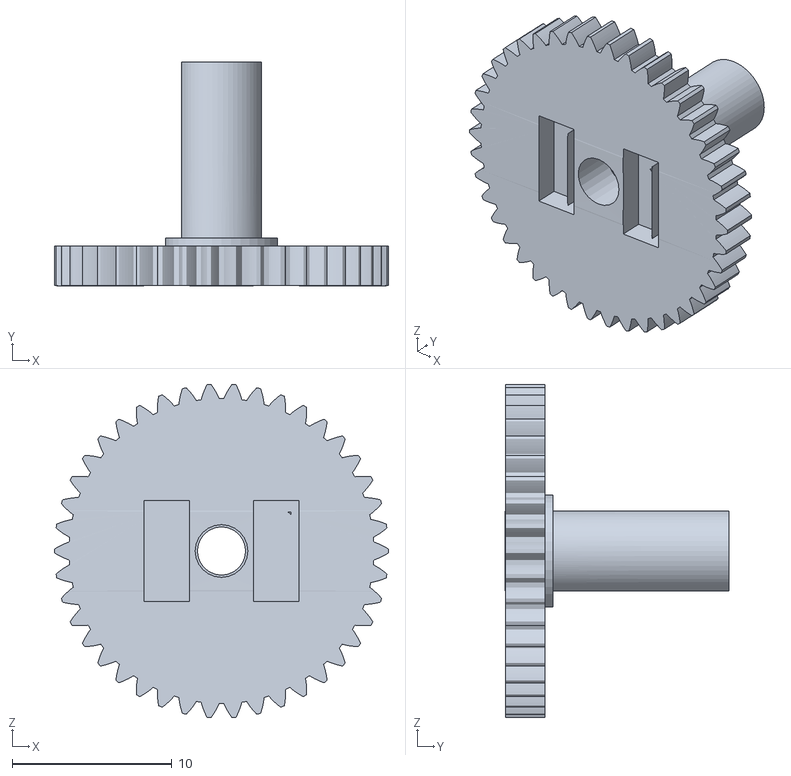
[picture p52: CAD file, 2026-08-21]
models/Eva01/engranaje.stl
20.9 x 14.0 x 20.9

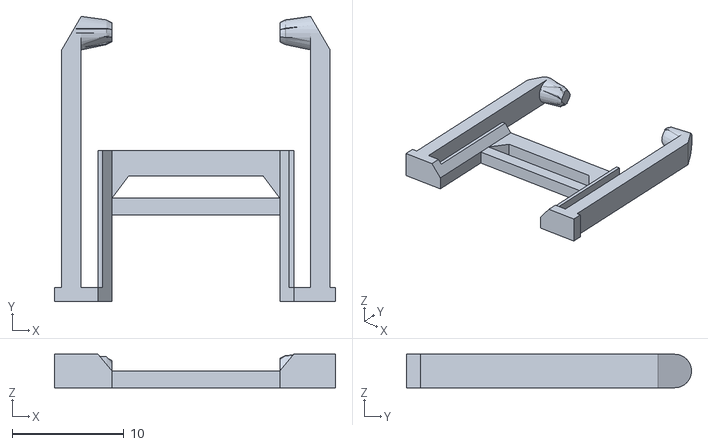
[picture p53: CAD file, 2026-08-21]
models/Eva01/porta_resorte.stl
25.1 x 25.5 x 3.00

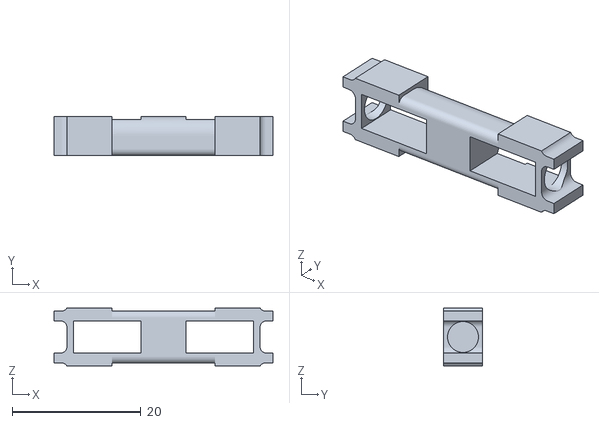
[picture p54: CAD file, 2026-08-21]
models/Eva01/Eje trasero.stl
34.0 x 6.00 x 9.00

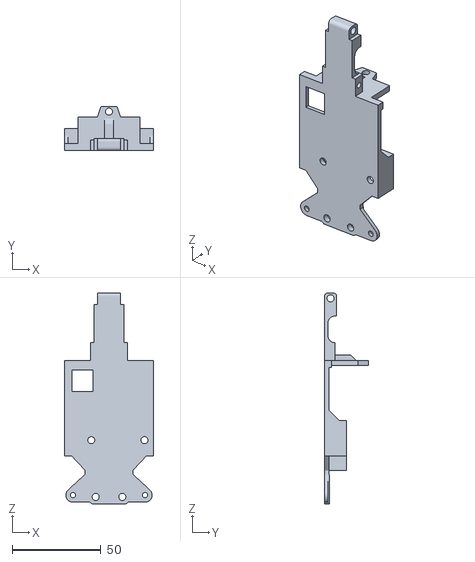
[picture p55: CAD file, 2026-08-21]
models/Eva01/base.stl
50.0 x 25.0 x 119.0

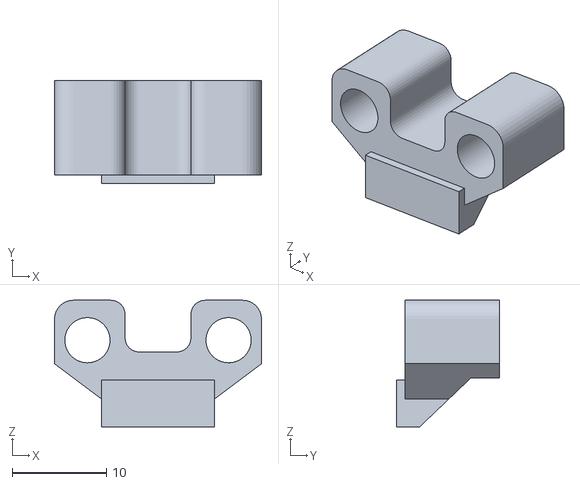
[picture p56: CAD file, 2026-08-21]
models/Eva01/restriccion direccion.stl
22.0 x 10.9 x 13.4

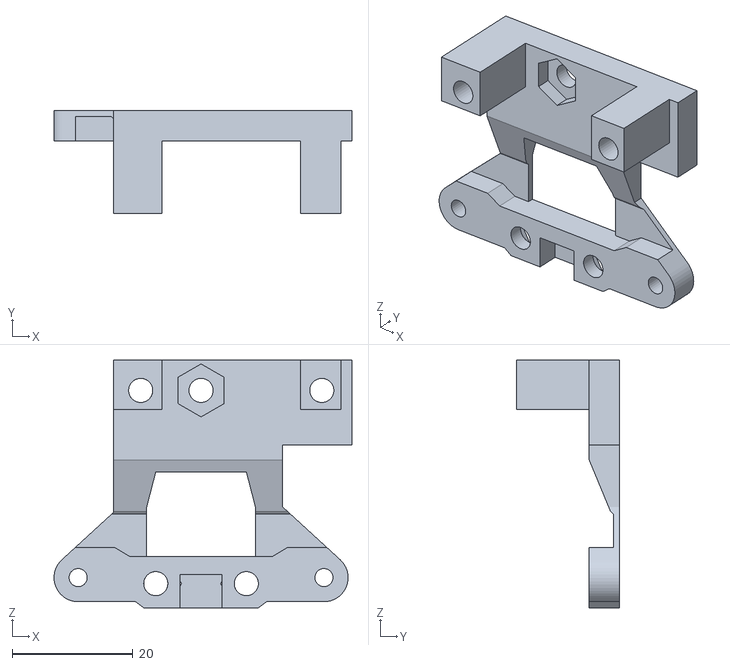
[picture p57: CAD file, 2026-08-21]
models/Eva01/tope-dir.stl
49.4 x 17.0 x 41.0

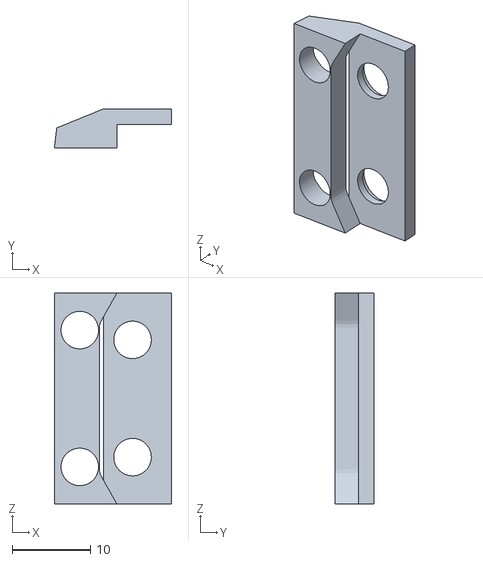
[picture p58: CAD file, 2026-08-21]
models/Eva01/conector.stl
15.0 x 5.00 x 27.0

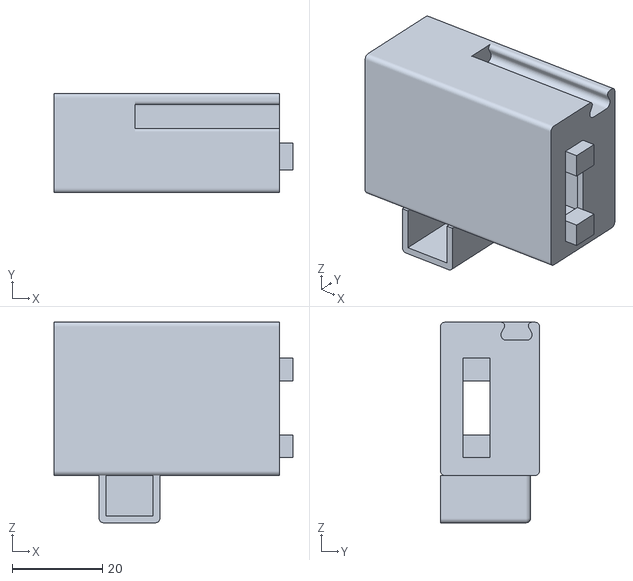
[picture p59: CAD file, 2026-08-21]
models/Eva01/Fuente de poder.stl
53.0 x 22.0 x 44.5

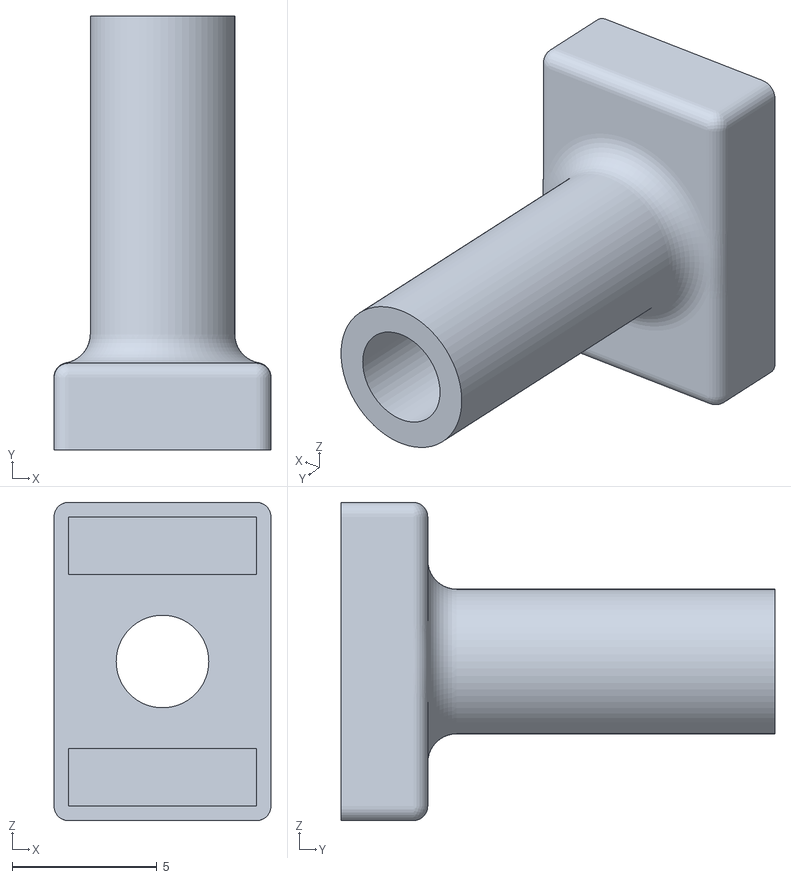
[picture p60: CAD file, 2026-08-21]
models/Eva01/conector eje trasero.stl
7.50 x 15.0 x 11.0

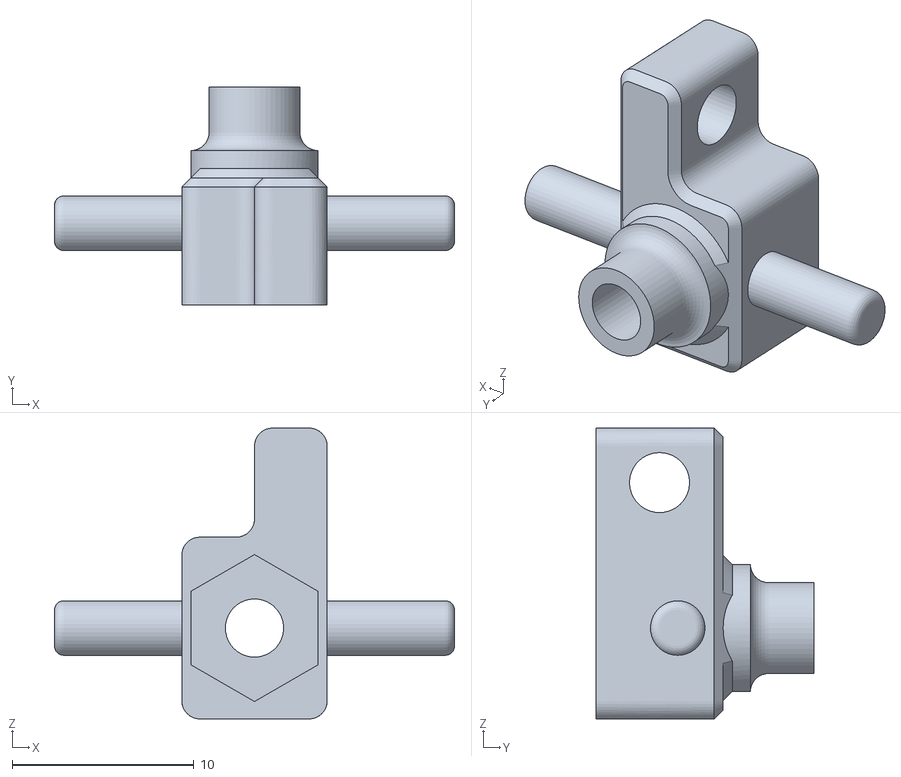
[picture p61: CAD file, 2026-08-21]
models/Eva01/Muñón.stl
22.0 x 12.0 x 16.0

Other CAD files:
models/Eva01/pin de sensores.stl
models/Eva01/Soporte rodamiento trasero - i.stl
models/Eva01/Tapa.stl
models/Eva01/Soporte rodamiento trasero - d.stl
models/Eva01/Caucho.stl
models/Eva01/Cauchos delanteros.stl
models/Eva01/Renault Team Genesis.f3z
models/Eva01/Rin v2.0.stl
models/Eva01/Soporte de sensores.stl
models/Eva01/Soporte motor.stl
models/Eva01/Soporte rodamiento trasero v2.stl
models/Eva01/Soporte suspension trasera.stl
models/Eva01/barra direccion.stl
models/Eva01/marco-suspension.stl

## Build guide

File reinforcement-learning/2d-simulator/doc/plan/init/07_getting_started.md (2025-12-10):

# 実装開始ガイド

## 1. 開発環境のセットアップ

### 1.1 前提条件

- Python 3.8以上（3.9推奨）
- Git
- （オプション）CUDA対応GPU（学習の高速化）

### 1.2 初期セットアップ手順

#### Step 1: リポジトリのクローン
```bash
cd /Users/akamite/Documents/ichis/minicar-battle/reinforcement-learning/2d-simulator
git status  # 既に初期化済みを確認
```

#### Step 2: 仮想環境の作成
```bash
# venvを使用
python3 -m venv venv
source venv/bin/activate  # Linux/macOS

# または conda
conda create -n minicar-rl python=3.9
conda activate minicar-rl
```

#### Step 3: 依存パッケージのインストール
```bash
# requirements.txtを作成後
pip install -r requirements.txt

# または段階的にインストール
pip install numpy scipy
pip install pybox2d
pip install torch torchvision
pip install gymnasium
pip install pygame matplotlib
pip install tensorboard
pip install pyyaml
pip install pytest black flake8
```

#### Step 4: ディレクトリ構造の作成
```bash
# スクリプトで一括作成
mkdir -p src/{env,physics,rl,curriculum,domain_randomization,utils,deploy}
mkdir -p courses/{easy,medium,hard}
mkdir -p configs
mkdir -p scripts
mkdir -p tests
mkdir -p notebooks
mkdir -p models/{checkpoints,best}
mkdir -p logs/{tensorboard,training}
mkdir -p doc/{design,api}

# __init__.pyファイルの作成
touch src/__init__.py
touch src/env/__init__.py
touch src/physics/__init__.py
touch src/rl/__init__.py
touch src/curriculum/__init__.py
touch src/domain_randomization/__init__.py
touch src/utils/__init__.py
touch src/deploy/__init__.py
```

#### Step 5: .gitignoreの作成
```bash
cat > .gitignore << 'EOF'
# Python
__pycache__/
*.py[cod]
*$py.class
*.so
.Python
venv/
env/
ENV/
.venv

# IDEs
.vscode/
.idea/
*.swp
*.swo
*~

# Logs and databases
*.log
*.sqlite
logs/
*.db

# Models
models/checkpoints/*.pth
models/checkpoints/*.pt

# Jupyter
.ipynb_checkpoints/
*.ipynb_checkpoints

# OS
.DS_Store
Thumbs.db

# TensorBoard
events.out.tfevents.*

# Temporary files
tmp/
temp/
*.tmp
EOF
```

#### Step 6: requirements.txtの作成
```bash
cat > requirements.txt << 'EOF'
# Core
numpy==1.24.0
scipy==1.10.0

# Physics
pybox2d==2.3.10

# RL Framework
torch==2.0.0
torchvision==0.15.0
gymnasium==0.29.0

# Visualization
pygame==2.5.0
matplotlib==3.7.0

# Logging
tensorboard==2.13.0

# Config
pyyaml==6.0

# Testing
pytest==7.3.0
pytest-cov==4.1.0

# Code Quality
black==23.3.0
flake8==6.0.0

# Deployment
onnxruntime==1.15.0
EOF
```

#### Step 7: setup.pyの作成（オプション）
```python
# setup.py
from setuptools import setup, find_packages

setup(
    name="minicar-2d-simulator",
    version="0.1.0",
    packages=find_packages(),
    install_requires=[
        "numpy>=1.24.0",
        "scipy>=1.10.0",
        "pybox2d>=2.3.10",
        "torch>=2.0.0",
        "gymnasium>=0.29.0",
        "pygame>=2.5.0",
        "matplotlib>=3.7.0",
        "tensorboard>=2.13.0",
        "pyyaml>=6.0",
    ],
    python_requires=">=3.8",
)
```

---

## 2. Phase 1の実装順序

### Week 1: Day 1-2

#### タスク1: Box2Dの動作確認
```python
# tests/test_box2d_basic.py
from Box2D import b2World, b2Vec2

def test_box2d_installation():
    """Box2Dが正しくインストールされているか確認"""
    world = b2World(gravity=(0, 0), doSleep=True)
    assert world is not None

def test_create_body():
    """簡単なボディを作成"""
    world = b2World(gravity=(0, 0))
    body = world.CreateDynamicBody(position=(0, 0))
    body.CreateCircleFixture(radius=1, density=1)

    # シミュレーション
    for _ in range(60):
        world.Step(1/60, 6, 2)

    assert body is not None
```

実行:
```bash
pytest tests/test_box2d_basic.py -v
```

#### タスク2: PhysicsWorldの実装
```python
# src/physics/box2d_wrapper.py
from Box2D import b2World, b2Vec2, b2Body, b2PolygonShape
from typing import List, Tuple

class PhysicsWorld:
    def __init__(self, gravity: Tuple[float, float] = (0, 0)):
        self.world = b2World(gravity=b2Vec2(*gravity), doSleep=True)
        self.time_step = 1.0 / 60.0
        self.vel_iters = 8
        self.pos_iters = 3

    def step(self):
        """物理シミュレーションを1ステップ進める"""
        self.world.Step(self.time_step, self.vel_iters, self.pos_iters)

    def add_static_box(self, center: Tuple[float, float],
                       width: float, height: float) -> b2Body:
        """静的な矩形を追加"""
        body = self.world.CreateStaticBody(
            position=b2Vec2(*center),
            shapes=b2PolygonShape(box=(width/2, height/2))
        )
        return body
```

テスト:
```python
# tests/test_physics_world.py
from src.physics.box2d_wrapper import PhysicsWorld

def test_physics_world_creation():
    world = PhysicsWorld()
    assert world is not None

def test_add_static_box():
    world = PhysicsWorld()
    box = world.add_static_box((5, 5), 1, 1)
    assert box is not None
    assert box.position.x == 5
    assert box.position.y == 5
```

### Week 1: Day 3-4

#### タスク3: Vehicleの基本実装
```python
# src/env/vehicle.py
from Box2D import b2World, b2Vec2, b2Body, b2PolygonShape
import numpy as np
from typing import Tuple, Dict

class Vehicle:
    def __init__(self, world: b2World,
                 start_pos: Tuple[float, float],
                 start_angle: float):
        self.world = world

        # パラメータ
        self.width = 0.2   # m
        self.length = 0.4  # m
        self.mass = 1.0    # kg

        self.max_steering_angle = 0.5  # rad
        self.max_motor_force = 20.0    # N

        # ボディ作成
        self.body = self.world.CreateDynamicBody(
            position=b2Vec2(*start_pos),
            angle=start_angle,
            linearDamping=0.5,
            angularDamping=0.8,
        )

        # 形状
        self.body.CreatePolygonFixture(
            box=(self.length/2, self.width/2),
            density=self.mass / (self.length * self.width),
            friction=0.7,
        )

    def apply_control(self, steering: float, throttle: float):
        """
        制御入力を適用

        Args:
            steering: -1.0 ~ 1.0
            throttle: 0.0 ~ 1.0
        """
        # ステアリング角度
        steer_angle = steering * self.max_steering_angle

        # 車両の向き
        angle = self.body.angle
        direction = b2Vec2(np.cos(angle + steer_angle),
                          np.sin(angle + steer_angle))

        # モーター力を適用
        force = throttle * self.max_motor_force * direction
        self.body.ApplyForceToCenter(force, True)

        # 横滑り抑制（簡易）
        self._apply_lateral_friction()

    def _apply_lateral_friction(self):
        """横方向の速度を抑制"""
        velocity = self.body.linearVelocity
        angle = self.body.angle

        # 車両座標系での速度
        forward = b2Vec2(np.cos(angle), np.sin(angle))
        lateral = b2Vec2(-np.sin(angle), np.cos(angle))

        lateral_vel = velocity.dot(lateral)

        # 横方向の速度を減衰
        impulse = -lateral_vel * self.mass * 0.5 * lateral
        self.body.ApplyLinearImpulse(impulse, self.body.position, True)

    def get_state(self) -> Dict:
        """現在の状態を取得"""
        return {
            'position': (self.body.position.x, self.body.position.y),
            'angle': self.body.angle,
            'velocity': (self.body.linearVelocity.x, self.body.linearVelocity.y),
            'angular_velocity': self.body.angularVelocity,
        }
```

テスト:
```python
# tests/test_vehicle.py
from src.physics.box2d_wrapper import PhysicsWorld
from src.env.vehicle import Vehicle

def test_vehicle_creation():
    world = PhysicsWorld()
    vehicle = Vehicle(world.world, (0, 0), 0)
    assert vehicle is not None

def test_vehicle_forward_motion():
    world = PhysicsWorld()
    vehicle = Vehicle(world.world, (0, 0), 0)

    # 前進
    for _ in range(100):
        vehicle.apply_control(steering=0.0, throttle=1.0)
        world.step()

    state = vehicle.get_state()
    # 前方（x正方向）に移動したか
    assert state['position'][0] > 1.0

def test_vehicle_turning():
    world = PhysicsWorld()
    vehicle = Vehicle(world.world, (0, 0), 0)

    # 右旋回
    for _ in range(100):
        vehicle.apply_control(steering=1.0, throttle=0.5)
        world.step()

    state = vehicle.get_state()
    # 角度が変化したか
    assert abs(state['angle']) > 0.1
```

### Week 1: Day 5

#### タスク4: 簡単なコース作成
```json
// courses/easy/simple_oval.json
{
  "name": "Simple Oval",
  "description": "シンプルな楕円コース",
  "start_position": [2.0, 5.0],
  "start_angle": 0.0,
  "goal_position": [2.0, 5.0],
  "goal_radius": 0.5,
  "walls": [
    {
      "type": "polygon",
      "vertices": [
        [0, 0], [10, 0], [10, 10], [0, 10]
      ]
    },
    {
      "type": "polygon",
      "vertices": [
        [2, 2], [8, 2], [8, 8], [2, 8]
      ]
    }
  ]
}
```

#### タスク5: Courseクラスの実装
```python
# src/env/course.py
import json
from typing import List, Tuple, Dict
from Box2D import b2World, b2Vec2, b2PolygonShape
import numpy as np

class Course:
    def __init__(self, course_file: str):
        with open(course_file, 'r') as f:
            self.data = json.load(f)

        self.walls = []

    def create_walls(self, world: b2World):
        """Box2Dの静的bodyとして壁を生成"""
        for wall_data in self.data['walls']:
            vertices = wall_data['vertices']

            # 閉じたポリゴンとして各辺を作成
            for i in range(len(vertices)):
                v1 = vertices[i]
                v2 = vertices[(i + 1) % len(vertices)]

                # 線分として壁を作成
                self._create_wall_segment(world, v1, v2)

    def _create_wall_segment(self, world: b2World,
                            v1: List[float], v2: List[float]):
        """2点間に壁を作成"""
        # 中点
        center = [(v1[0] + v2[0]) / 2, (v1[1] + v2[1]) / 2]

        # 長さと角度
        dx = v2[0] - v1[0]
        dy = v2[1] - v1[1]
        length = np.sqrt(dx**2 + dy**2)
        angle = np.arctan2(dy, dx)

        # 静的ボディ作成
        body = world.CreateStaticBody(
            position=b2Vec2(*center),
            angle=angle,
            shapes=b2PolygonShape(box=(length/2, 0.05))  # 薄い矩形
        )
        self.walls.append(body)

    def get_start_pose(self) -> Tuple[Tuple[float, float], float]:
        """スタート位置と角度"""
        pos = tuple(self.data['start_position'])
        angle = self.data['start_angle']
        return pos, angle
```

---

## 3. 開発ワークフロー

### 3.1 日々の開発サイクル

1. **朝**: タスクの確認、目標設定
2. **午前**: 実装 + ユニットテスト
3. **午後**: 統合テスト + デバッグ
4. **夕方**: コードレビュー、コミット

### 3.2 テスト駆動開発

```bash
# 開発サイクル
# 1. テストを書く
vim tests/test_vehicle.py

# 2. テストが失敗することを確認
pytest tests/test_vehicle.py

# 3. 実装
vim src/env/vehicle.py

# 4. テストがパスすることを確認
pytest tests/test_vehicle.py

# 5. リファクタリング
# 6. 再度テスト
```

### 3.3 コードフォーマット

```bash
# コードフォーマット
black src/ tests/

# リンター
flake8 src/ tests/

# 型チェック（オプション）
mypy src/
```

---

## 4. デバッグのヒント

### 4.1 Pygameデバッグ表示

```python
# 車両の状態をデバッグ表示
def render_debug_info(screen, vehicle):
    import pygame
    font = pygame.font.Font(None, 24)

    state = vehicle.get_state()
    texts = [
        f"Pos: ({state['position'][0]:.2f}, {state['position'][1]:.2f})",
        f"Angle: {state['angle']:.2f}",
        f"Vel: {np.linalg.norm(state['velocity']):.2f}",
    ]

    y_offset = 10
    for text in texts:
        surface = font.render(text, True, (255, 255, 255))
        screen.blit(surface, (10, y_offset))
        y_offset += 30
```

### 4.2 ログ出力

```python
import logging

logging.basicConfig(
    level=logging.INFO,
    format='%(asctime)s - %(name)s - %(levelname)s - %(message)s'
)

logger = logging.getLogger(__name__)
logger.info("Vehicle position: %s", vehicle.get_state()['position'])
```

---

## 5. 次のステップ

Phase 1のタスクを完了したら:

1. **動作確認**: 手動制御で走行テスト
2. **デモ動画**: 録画して記録
3. **レビュー**: コードレビュー実施
4. **Phase 2へ**: PPO実装に進む

---

## まとめ

このガイドに従って段階的に実装を進めることで、着実にプロジェクトを進めることができます。特にテスト駆動開発を意識し、各コンポーネントが独立して動作することを確認しながら進めてください。

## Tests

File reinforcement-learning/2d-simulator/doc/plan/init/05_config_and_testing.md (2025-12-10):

# 設定ファイルとテスト戦略

## 1. 設定ファイルのサンプル

### 1.1 環境設定 (configs/env_config.yaml)

```yaml
# 環境設定
env:
  # コース設定
  course_file: "courses/easy/simple_oval.json"

  # 車両パラメータ
  vehicle:
    width: 0.2        # m
    length: 0.4       # m
    mass: 1.0         # kg
    max_steering_angle: 0.5  # rad (約28度)
    max_motor_force: 20.0    # N
    friction_coefficient: 0.7

  # LiDARセンサー
  lidar:
    num_rays: 72
    max_range: 10.0   # m
    angle_min: 0      # rad
    angle_max: 6.28   # rad (2π)
    noise_level: 0.01 # 距離の1%のノイズ

  # シミュレーション
  simulation:
    time_step: 0.05   # 20Hz
    max_episode_steps: 2000
    physics_substeps: 4

  # レンダリング
  rendering:
    enabled: true
    fps: 30
    screen_width: 800
    screen_height: 600
    pixels_per_meter: 50

# 報酬設定
reward:
  # 前進報酬
  progress_reward: 1.0
  speed_reward: 0.1

  # ペナルティ
  time_penalty: -0.01
  wall_proximity_threshold: 0.3
  wall_proximity_penalty: -10.0
  collision_penalty: -100.0

  # ボーナス
  goal_bonus: 500.0
  checkpoint_bonus: 50.0
```

### 1.2 学習設定 (configs/training_config.yaml)

```yaml
# PPO設定
ppo:
  learning_rate: 3.0e-4
  batch_size: 256
  num_epochs: 10
  clip_ratio: 0.2
  entropy_coef: 0.01
  value_coef: 0.5
  max_grad_norm: 0.5

  # GAE
  gamma: 0.99
  gae_lambda: 0.95

# バッファ設定
buffer:
  capacity: 4096

# 学習ループ
training:
  total_timesteps: 1000000
  eval_frequency: 10000
  save_frequency: 50000
  num_eval_episodes: 10

  # 学習率スケジュール
  lr_schedule:
    type: "linear"  # constant, linear, exponential
    final_lr: 1.0e-5

# カリキュラム学習
curriculum:
  enabled: true
  courses:
    - "courses/easy/wide_oval.json"
    - "courses/medium/narrow_oval.json"
    - "courses/hard/shortcut_1.json"
  success_threshold: 0.8
  min_episodes_per_level: 50

# Domain Randomization
domain_randomization:
  enabled: true
  physics:
    friction_range: [0.5, 1.5]
    mass_range: [0.8, 1.2]
    motor_delay_range: [0.0, 0.05]
  sensor:
    lidar_noise_range: [0.005, 0.02]
    lidar_dropout_prob: 0.05

# ロギング
logging:
  tensorboard_dir: "logs/tensorboard"
  log_frequency: 100  # ステップごと
  video_frequency: 10000  # 動画保存頻度
```

### 1.3 モデル設定 (configs/model_config.yaml)

```yaml
# ポリシーネットワーク
policy:
  hidden_sizes: [256, 256]
  activation: "relu"
  log_std_init: -0.5

# 価値関数ネットワーク
value:
  hidden_sizes: [256, 256]
  activation: "relu"

# 正規化
normalization:
  obs_normalize: true
  reward_normalize: true
  clip_obs: 10.0
  clip_reward: 10.0
```

---

## 2. テスト戦略

### 2.1 ユニットテスト

#### 環境テスト (tests/test_env.py)
```python
import pytest
from src.env.minicar_env import MinicarEnv

def test_env_reset():
    """環境リセットのテスト"""
    env = MinicarEnv(config)
    obs, info = env.reset()

    assert obs.shape == (77,)
    assert 'position' in info

def test_env_step():
    """ステップ実行のテスト"""
    env = MinicarEnv(config)
    env.reset()

    action = np.array([0.0, 0.5])  # まっすぐ前進
    obs, reward, terminated, truncated, info = env.step(action)

    assert obs.shape == (77,)
    assert isinstance(reward, float)
    assert isinstance(terminated, bool)

def test_collision_detection():
    """衝突検出のテスト"""
    env = MinicarEnv(config)
    env.reset()

    # 壁に向かって全速力
    for _ in range(100):
        obs, reward, terminated, truncated, info = env.step([1.0, 1.0])
        if terminated:
            assert reward < -50  # 衝突ペナルティ
            break
```

#### 車両テスト (tests/test_vehicle.py)
```python
def test_vehicle_motion():
    """車両の動きのテスト"""
    world = PhysicsWorld()
    vehicle = Vehicle(world.world, (0, 0), 0)

    # 前進
    vehicle.apply_control(steering=0.0, throttle=1.0)
    for _ in range(100):
        world.step()

    # 前方に移動したか確認
    assert vehicle.get_state()['position'][0] > 0

def test_steering():
    """ステアリングのテスト"""
    world = PhysicsWorld()
    vehicle = Vehicle(world.world, (0, 0), 0)

    # 右に旋回
    vehicle.apply_control(steering=1.0, throttle=0.5)
    for _ in range(100):
        world.step()

    # 角度が変化したか確認
    assert abs(vehicle.get_state()['angle']) > 0.1
```

#### LiDARテスト (tests/test_sensors.py)
```python
def test_lidar_scan():
    """LiDARスキャンのテスト"""
    world = PhysicsWorld()
    # 簡単な壁を作成
    world.add_static_polygon([(5, -5), (5, 5), (5.1, 5), (5.1, -5)])

    lidar = LiDARSensor(world.world)
    distances = lidar.scan(position=(0, 0), orientation=0)

    assert len(distances) == 72
    assert np.min(distances) > 0
    assert np.min(distances) < lidar.max_range

def test_lidar_noise():
    """LiDARノイズのテスト"""
    lidar = LiDARSensor(...)
    clean_scan = np.ones(72) * 5.0

    noisy_scan = lidar.add_noise(clean_scan, noise_level=0.1)

    # ノイズが追加されている
    assert not np.allclose(clean_scan, noisy_scan)
    # 範囲内
    assert np.all(noisy_scan >= 0)
```

#### PPOテスト (tests/test_ppo.py)
```python
def test_policy_forward():
    """ポリシーの順伝播テスト"""
    policy = GaussianPolicy(obs_dim=77, action_dim=2)
    obs = torch.randn(32, 77)

    mean, log_std = policy.forward(obs)

    assert mean.shape == (32, 2)
    assert log_std.shape == (32, 2)

def test_policy_sample():
    """ポリシーのサンプリングテスト"""
    policy = GaussianPolicy(obs_dim=77, action_dim=2)
    obs = torch.randn(32, 77)

    action, log_prob = policy.sample(obs)

    assert action.shape == (32, 2)
    assert log_prob.shape == (32,)

def test_ppo_update():
    """PPO更新のテスト"""
    policy = GaussianPolicy(...)
    value = ValueNetwork(...)
    ppo = PPO(policy, value, config)

    buffer = create_dummy_buffer()

    stats = ppo.update(buffer)

    assert 'policy_loss' in stats
    assert 'value_loss' in stats
```

### 2.2 統合テスト

#### エンドツーエンドテスト
```python
def test_full_training_loop():
    """完全な学習ループのテスト（短時間版）"""
    env = MinicarEnv(config)
    policy = GaussianPolicy(...)
    value = ValueNetwork(...)
    ppo = PPO(policy, value, config)

    # 100エピソードだけ学習
    for episode in range(100):
        obs, _ = env.reset()
        done = False

        while not done:
            action, log_prob = policy.sample(torch.from_numpy(obs))
            next_obs, reward, terminated, truncated, info = env.step(action.numpy())
            done = terminated or truncated
            obs = next_obs

        if episode % 10 == 0:
            ppo.update(buffer)

    # 学習が進んでいることを確認
    assert get_average_reward() > initial_reward
```

### 2.3 パフォーマンステスト

```python
def test_simulation_speed():
    """シミュレーション速度のテスト"""
    env = MinicarEnv(config)
    env.reset()

    start_time = time.time()
    for _ in range(1000):
        env.step(env.action_space.sample())
    elapsed = time.time() - start_time

    # 1000ステップが1秒以内
    assert elapsed < 1.0

def test_training_throughput():
    """学習スループットのテスト"""
    # リアルタイムの10倍以上のスピード目標
    ...
```

### 2.4 CI/CD設定

#### GitHub Actions (.github/workflows/test.yml)
```yaml
name: Tests

on: [push, pull_request]

jobs:
  test:
    runs-on: ubuntu-latest

    steps:
    - uses: actions/checkout@v3

    - name: Set up Python
      uses: actions/setup-python@v4
      with:
        python-version: '3.9'

    - name: Install dependencies
      run: |
        pip install -r requirements.txt
        pip install pytest pytest-cov

    - name: Run tests
      run: |
        pytest tests/ --cov=src --cov-report=xml

    - name: Upload coverage
      uses: codecov/codecov-action@v3
```

---

## 3. デバッグとトラブルシューティング

### 3.1 よくある問題

#### 問題1: 学習が収束しない
**症状:** 報酬が増えない、ランダムな動きを続ける

**チェック項目:**
1. 報酬スケールが適切か（報酬の範囲を確認）
2. 学習率が適切か（大きすぎる/小さすぎる）
3. 観測の正規化が機能しているか
4. ポリシーのエントロピーが十分か（探索が足りない）

**解決策:**
```python
# 報酬の範囲を確認
print(f"Reward range: {np.min(rewards)} to {np.max(rewards)}")

# エントロピーを増やす
config['entropy_coef'] = 0.05  # デフォルト0.01から増加

# 学習率を調整
config['learning_rate'] = 1e-4
```

#### 問題2: シミュレーションが遅い
**症状:** リアルタイムより遅い

**チェック項目:**
1. レンダリングが有効になっていないか
2. 物理演算のサブステップが多すぎないか
3. LiDARのレイ数が多すぎないか

**解決策:**
```yaml
# レンダリングを無効化
rendering:
  enabled: false

# 物理サブステップを減らす
simulation:
  physics_substeps: 2  # デフォルト4から削減
```

#### 問題3: 壁を抜ける
**症状:** 車両が壁をすり抜ける

**チェック項目:**
1. 物理ステップが大きすぎる
2. 車両速度が速すぎる
3. 衝突検出が機能していない

**解決策:**
```yaml
simulation:
  time_step: 0.02  # より小さいステップ
  physics_substeps: 8  # サブステップを増やす

vehicle:
  max_motor_force: 10.0  # 最大力を減らす
```

### 3.2 可視化とデバッグツール

#### 学習曲線の可視化
```python
# scripts/plot_learning_curve.py
import matplotlib.pyplot as plt
from tensorboard.backend.event_processing import event_accumulator

def plot_rewards(log_dir):
    ea = event_accumulator.EventAccumulator(log_dir)
    ea.Reload()

    rewards = ea.Scalars('reward/episode')
    steps = [r.step for r in rewards]
    values = [r.value for r in rewards]

    plt.plot(steps, values)
    plt.xlabel('Steps')
    plt.ylabel('Episode Reward')
    plt.title('Learning Curve')
    plt.savefig('learning_curve.png')
```

#### 軌跡の可視化
```python
# scripts/visualize_trajectory.py
def visualize_trajectory(model_path, course_path):
    env = MinicarEnv(...)
    policy = load_model(model_path)

    obs, _ = env.reset()
    trajectory = []

    for _ in range(1000):
        action, _ = policy.sample(obs)
        obs, reward, done, _, info = env.step(action)
        trajectory.append(info['position'])

        if done:
            break

    # 軌跡をプロット
    trajectory = np.array(trajectory)
    plt.plot(trajectory[:, 0], trajectory[:, 1])
    plt.savefig('trajectory.png')
```

---

## 4. ベストプラクティス

### 4.1 開発フロー

1. **機能ブランチ**: `feature/lidar-sensor`
2. **テスト駆動開発**: 先にテストを書く
3. **コードレビュー**: PRでレビュー
4. **CI/CD**: 自動テスト実行
5. **マージ**: `develop` → `main`

### 4.2 コミットメッセージ

```
[type] 簡潔な説明

詳細な説明（必要に応じて）

type: feat, fix, docs, test, refactor
```

例:
```
[feat] LiDARセンサーのノイズモデルを実装

ガウシアンノイズとドロップアウトを追加。
Domain Randomizationで使用。
```

### 4.3 ドキュメント

- **docstring**: すべての関数・クラスに記述
- **型ヒント**: 可能な限り使用
- **README**: セットアップ手順を明記
- **CHANGELOG**: 変更履歴を記録

---

## 5. パフォーマンスチューニング

### 5.1 学習の高速化

1. **並列環境**: 複数の環境を並列実行
```python
from gymnasium.vector import AsyncVectorEnv

envs = AsyncVectorEnv([
    lambda: MinicarEnv(config) for _ in range(8)
])
```

2. **GPU活用**: ネットワーク計算をGPUで実行
```python
device = torch.device("cuda" if torch.cuda.is_available() else "cpu")
policy.to(device)
value.to(device)
```

3. **効率的なバッファ**: NumPy配列を使用

### 5.2 推論の高速化

1. **ONNX変換**: 実機デプロイ用
2. **モデル量子化**: 精度を維持しつつサイズ削減
3. **バッチ推論**: 可能であればバッチで処理

---

## まとめ

テスト戦略と設定管理を適切に行うことで、開発効率と品質を向上させることができます。特にユニットテストは開発の初期段階から導入し、継続的にメンテナンスすることが重要です。

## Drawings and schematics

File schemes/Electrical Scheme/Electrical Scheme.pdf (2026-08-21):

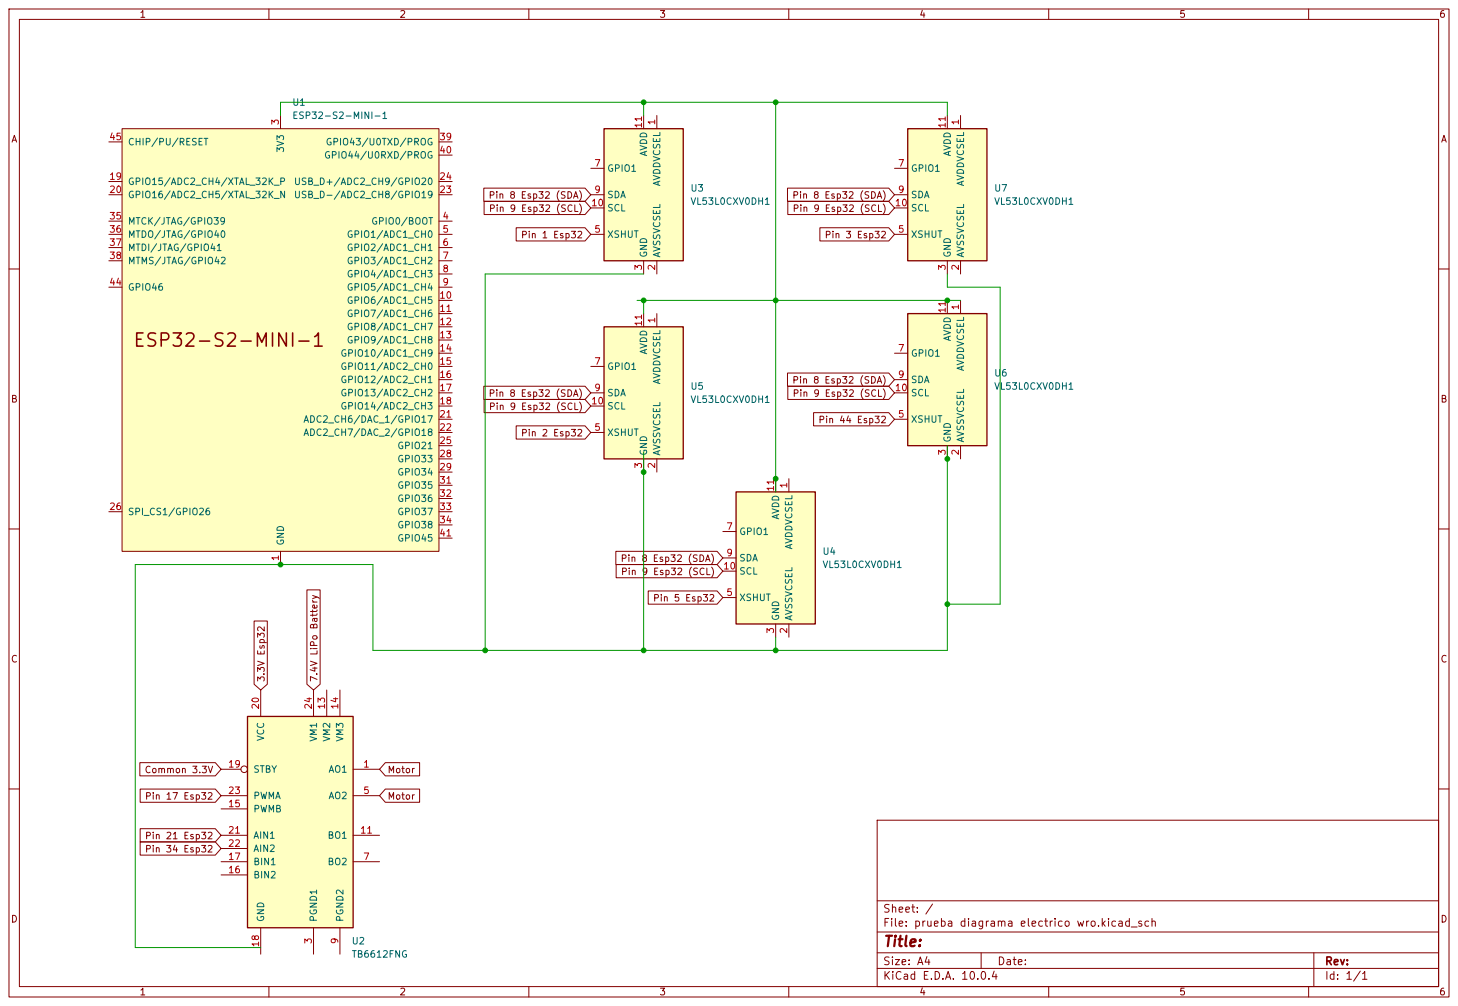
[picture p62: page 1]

Pin 3 Esp32 Pin 8 Esp32 (SDA) Pin 9 Esp32 (SCL)
Sheet: / AVDDVCSEL 1 AVSSVCSEL 2 GND 3

File: prueba diagrama electrico wro.kicad_sch
Title:

Size: A4 | Rev:
KiCad E.D.A. 10.0.4 | Id: 1/1

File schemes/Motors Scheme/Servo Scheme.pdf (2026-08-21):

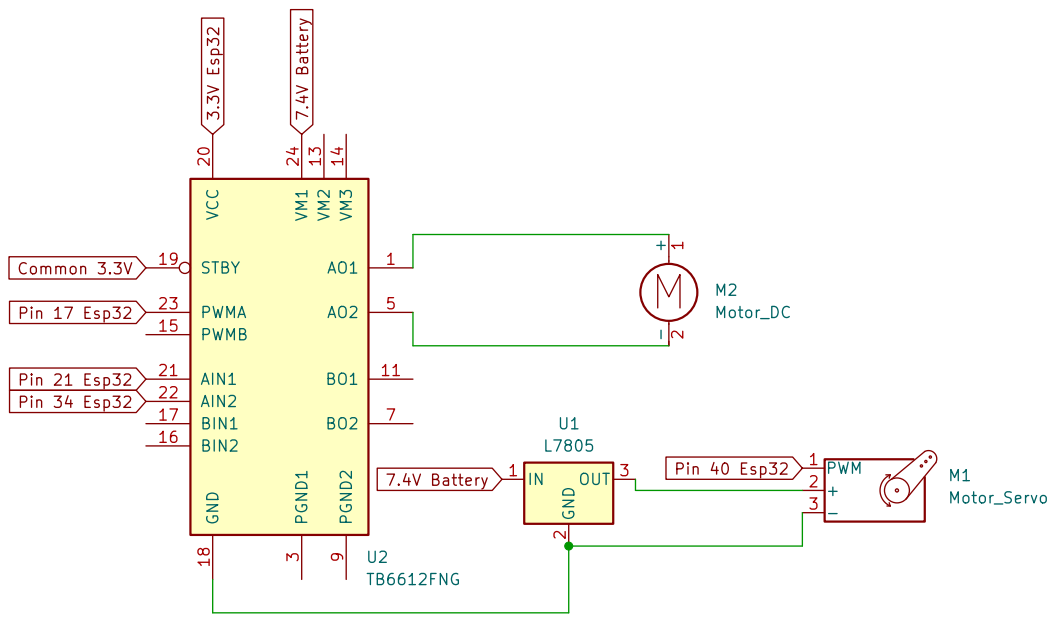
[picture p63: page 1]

Sheet: /
File: Diagrama servo motor.kicad_sch
Title:

Size: A4 | Rev:
KiCad E.D.A. 10.0.4 | Id: 1/1

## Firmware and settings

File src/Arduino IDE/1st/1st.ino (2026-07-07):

/*
 * main.ino
 *
 * Control de Follow-the-Gap + Pure Pursuit con 5 sensores VL53L0X (XSHUT)
 * Adaptado para ESP32-S2 Mini y Driver de tracción TB6612FNG.
 * * El carro correrá de forma autónoma durante exactamente 1 minuto y luego se detendrá.
 */

#include "Actuator.h"
#include "Config.h"
#include "GapFinder.h"
#include "Logger.h"
#include "SensorReader.h"
#include "SteeringController.h"

// ============================================================================
// Variables Globales
// ============================================================================
SensorReader sensorReader;
GapFinder gapFinder;
SteeringController steeringController;
Actuator actuator;

// Variables para el control de tiempo de la carrera
unsigned long tiempoInicioCarrera = 0;
bool carreraTerminada = false;
const unsigned long DURACION_CARRERA_MS = 60000; // 1 minuto = 60,000 ms

// ============================================================================
// setup
// ============================================================================
void setup() {
    // Inicializar el puerto de diagnóstico serial si el modo actual lo permite
    #if ENABLE_SERIAL
    Serial.begin(115200);
    while (!Serial) { delay(10); } // Esperar conexión en el ESP32-S2 Mini
    #endif

    Logger::println("=== INICIANDO ROBOT (ESP32-S2 Mini) ===");

    // 1. Inicializar actuadores (Servo en pin 18 y TB6612FNG)
    actuator.begin();

    // 2. Inicializar los 5 sensores secuencialmente mediante XSHUT
    if (!sensorReader.begin()) {
        Logger::println("¡ERROR CRÍTICO! Falló la inicialización de sensores. Sistema congelado.");
        actuator.stop();
        while (1) { delay(100); }
    }

    steeringController.begin();

    Logger::println("=== Setup completado con éxito ===");
    Logger::println("Alineando dirección y esperando inicio de carrera...");
    
    actuator.setSteering(0.0);
    actuator.stop();
    
    delay(1000); // Pequeña pausa de seguridad antes de arrancar

    // Guardamos el tiempo exacto en milisegundos en el que arranca la carrera
    tiempoInicioCarrera = millis();
    Logger::println("!!! ¡CARRERA INICIADA! Cronómetro en marcha (1 min) !!!");
}

// ============================================================================
// loop
// ============================================================================
void loop() {
    // Si el minuto ya pasó, forzamos que el coche se quede estático y no haga nada más
    if (carreraTerminada) {
        actuator.setSteering(0.0); // Centrar ruedas
        actuator.stop();           // Apagar motor
        delay(500);
        return; 
    }

    // Comprobar si el tiempo actual ha superado el minuto desde que inició la carrera
    if (millis() - tiempoInicioCarrera >= DURACION_CARRERA_MS) {
        carreraTerminada = true;
        Logger::println("\n==============================================");
        Logger::println("¡TIEMPO AGOTADO! 1 minuto completado. Deteniendo robot.");
        Logger::println("==============================================");
        return;
    }

    // =========================================================================
    // Ejecución del algoritmo de control autónomo (Solo si estamos dentro del minuto)
    // =========================================================================
    unsigned long loopStartUs = micros();

    // Fase 1: Leer los 5 sensores ToF mediante direccionamiento I2C directo
    unsigned long sensStartUs = micros();
    sensorReader.readAll();
    unsigned long sensElapsedUs = micros() - sensStartUs;

    const SensorData* sensorData = sensorReader.getAllData();

    // Fase 2: Comprobar parada de emergencia por proximidad crítica al frente
    // Usamos el nuevo FRONT_SENSOR_INDEX (índice 2) definido en tu Config.h
    bool parada_emergencia = sensorData[FRONT_SENSOR_INDEX].valid &&
                             (sensorData[FRONT_SENSOR_INDEX].distance < CRITICAL_STOP_THRESHOLD);

    // Fase 3: Procesar algoritmo Follow-the-Gap
    GapResult gap = gapFinder.find(sensorData);

    #if ENABLE_SERIAL
    float distancia_frontal = sensorData[FRONT_SENSOR_INDEX].valid
                           ? sensorData[FRONT_SENSOR_INDEX].distance
                           : 0.0f;
    Logger::printGapResult(gap.target_angle, distancia_frontal);
    #endif

    // Fase 4: Calcular ángulo de dirección óptimo usando Pure Pursuit
    float angulo_giro_calculado = steeringController.calculate(gap, sensorData);

    #if ENABLE_SERIAL
    Logger::printSteering(angulo_giro_calculado);
    #endif

    // Fase 5: Enviar comandos a los Actuadores
    if (parada_emergencia) {
        // Si hay un obstáculo insalvable al frente, frena por seguridad antes del minuto
        Logger::println("¡ALERTA! Parada de emergencia por proximidad.");
        actuator.setSteering(0.0);
        actuator.stop();
    } else {
        // Conducción normal: Ajusta el servo e inyecta la velocidad PWM de crucero
        actuator.setSteering(angulo_giro_calculado);
        actuator.setSpeed(CRUISE_SPEED); // Usa el nuevo valor discreto 0-255 de tu Config.h
    }

    // Telemetría de tiempos del ciclo
    #if ENABLE_SERIAL
    unsigned long loopEndUs = micros();
    unsigned long loopElapsedUs = loopEndUs - loopStartUs;
    Logger::printLoopTiming(loopElapsedUs, sensElapsedUs);
    Logger::println("");
    #endif
}

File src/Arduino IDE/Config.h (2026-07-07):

/*
 * Config.h
 *
 * Centralized configuration values.
 * All constants are named here to avoid magic numbers.
 */

#ifndef CONFIG_H
#define CONFIG_H

// ============================================================================
// Run mode
// ============================================================================
// Mode definitions:
//   0: MODE_DEBUG      - debug only (no PWM, serial enabled)
//   1: MODE_PRODUCTION - race run (PWM enabled, serial disabled)
//   2: MODE_DEBUG_RUN  - debug run (PWM enabled, serial enabled)
#define MODE_DEBUG 0
#define MODE_PRODUCTION 1
#define MODE_DEBUG_RUN 2

#define RUN_MODE MODE_PRODUCTION // select run mode here

// Feature toggles derived from RUN_MODE
#define ENABLE_SERIAL (RUN_MODE == MODE_DEBUG || RUN_MODE == MODE_DEBUG_RUN)
#define ENABLE_PWM (RUN_MODE == MODE_PRODUCTION || RUN_MODE == MODE_DEBUG_RUN)

// ============================================================================
// Hardware & Sensores ToF VL53L0X (Secuencia XSHUT)
// ============================================================================
// Ya no usamos el multiplexor TCA9548A_ADDR ni SENSOR_CHANNELS.
// Pines físicos conectados a los XSHUT de cada sensor en el ESP32-S2 Mini
const uint8_t XSHUT_PINS[5] = {1, 2, 3, 4, 5}; 

// Direcciones I2C dinámicas asignadas consecutivamente durante el inicio
const uint8_t SENSOR_ADDRESSES[5] = {0x30, 0x32, 0x34, 0x36, 0x38};

// Nueva distribución de 5 sensores
const uint8_t NUM_SENSORS = 5;

// Ángulos físicos de orientación: [Izquierda 90°, Izquierda 45°, Centro 0°, Derecha 45°, Derecha 90°]
const float SENSOR_ANGLES[NUM_SENSORS] = {-90.0f, -45.0f, 0.0f, 45.0f, 90.0f};

// El sensor central (0.0 grados) ahora pasa a estar en el índice 2
const uint8_t FRONT_SENSOR_INDEX = 2;  

// ============================================================================
// Sensor Thresholds & Parameters
// ============================================================================
const uint16_t RELIABLE_RANGE = 2300;       // Max trusted distance (mm)
const uint16_t MIN_VALID_DISTANCE = 40;     // Min trusted distance (mm)
const uint16_t CRITICAL_STOP_THRESHOLD = 300; // Front emergency-stop threshold (mm)

// Auto-stop timeout (debug aid).
// 0 disables it; otherwise the car stops after this many seconds.
const unsigned long AUTO_STOP_SECONDS = 20;

// ============================================================================
// Actuadores: Servo de Dirección (Calibración en Grados)
// ============================================================================
const uint8_t SERVO_PIN = 40;        // Pin de señal del servo (probado en sweep)

// --- AJUSTA ESTOS VALORES EN GRADOS SEGÚN TU COCHE ---
const int SERVO_CENTER_DEG = 60;     // Ángulo central para que el carro vaya recto
const int SERVO_RIGHT_MAX_DEG = 0;   // Ángulo físico máximo a la DERECHA
const int SERVO_LEFT_MAX_DEG = 120;   // Ángulo físico máximo a la IZQUIERDA (puedes probar 80, 90, etc.)

const float MAX_STEERING_ANGLE = 30.0f; // Máximo ángulo de giro que el software (Pure Pursuit) puede calcular

// ============================================================================
// Actuadores: Motor de Tracción (TB6612FNG + Periférico LEDC)
// ============================================================================
const uint8_t MOTOR_IN1_PIN = 34;
const uint8_t MOTOR_IN2_PIN = 21;
const uint8_t MOTOR_PWMA_PIN = 17;

// Configuración de señal PWM por hardware nativo para ESP32-S2
const uint32_t PWM_FREQ = 20000;     // Frecuencia de 20kHz (Inaudible, evita silbidos del motor)
const uint8_t PWM_RESOLUTION = 8;    // Resolución de 8 bits (Valores de ciclo de trabajo de 0 a 255)

// Velocidad base de crucero para el circuito (Mapeado de 0 a 255)
const uint8_t CRUISE_SPEED = 150;    

// ============================================================================
// Pure Pursuit Parameters
// ============================================================================
const float WHEELBASE_MM = 92.0f;        // L: distance from front to rear axle
const float LOOKAHEAD_OFFSET_MM = 400.0f; // subtracted from front distance to get Ld

// ============================================================================
// Gap Finder Parameters
// ============================================================================
const float FARTHEST_HYSTERESIS = 150.0f; // candidate must be this much farther to switch (mm)

// ============================================================================
// Math constants & Trigonometry
// ============================================================================
#ifndef DEG_TO_RAD
#define DEG_TO_RAD 0.01745329251f
#endif

#ifndef RAD_TO_DEG
#define RAD_TO_DEG 57.295779513f
#endif

// Factor trigonométrico fijo sin(45°) usado en GapFinder.cpp para la interpolación de áreas
const float SIN_45_DEG = 0.7071067811f; 

#endif  // CONFIG_H

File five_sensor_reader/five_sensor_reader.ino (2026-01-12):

/*
 * five_sensor_reader.ino
 *
 * 5つのVL53L1Xセンサーを使った Follow the Gap + P制御
 *
 * 接続:
 * - TCA9548A I2Cマルチプレクサ (アドレス: 0x70)
 * - VL53L1Xセンサー → マルチプレクサのチャンネル0-4に接続
 * - サーボモーター → Pin 9
 * - ESC → Pin 10
 *
 * 使用方法:
 * 1. Arduino IDEでこのファイルを開く
 * 2. 必要なライブラリをインストール:
 *    - VL53L1X (Pololu)
 *    - Servo (Arduino標準ライブラリ)
 * 3. Config.hでRUN_MODEを設定
 *    - MODE_DEBUG: デバッグ専用（PWMなし、シリアルあり）
 *    - MODE_PRODUCTION: 本番走行（PWMあり、シリアルなし）
 *    - MODE_DEBUG_RUN: デバッグ走行（PWMあり、シリアルあり）
 * 4. Arduino Nano R4に書き込み
 */

#include "Actuator.h"
#include "Config.h"
#include "GapFinder.h"
#include "Logger.h"
#include "SensorReader.h"
#include "SteeringController.h"

// ============================================================================
// グローバルオブジェクト
// ============================================================================
SensorReader sensorReader;
GapFinder gapFinder;
SteeringController steeringController;
Actuator actuator;

// ============================================================================
// Setup関数
// ============================================================================
void setup() {
    // ロガー初期化（115200bpsで詳細データ表示）
    Logger::begin(115200);

    Logger::println("==========================================");
    Logger::println("  VL53L1X Follow the Gap + P Control");
    Logger::println("==========================================");
    Logger::print("Run Mode: ");
#if RUN_MODE == MODE_DEBUG
    Logger::println("DEBUG (No PWM, Serial ON)");
#elif RUN_MODE == MODE_PRODUCTION
    Logger::println("PRODUCTION (PWM ON, Serial OFF)");
#else
    Logger::println("DEBUG_RUN (PWM ON, Serial ON)");
#endif
    Logger::print("Measurement Interval: ");
    Logger::print(MEASUREMENT_INTERVAL);
    Logger::println("ms");
    Logger::print("Steering Kp: ");
    Logger::println(STEERING_KP);
    Logger::print("Steering Kd: ");
    Logger::println(STEERING_KD);
    Logger::println();

    // タイミング設定のサマリー表示
    Logger::printTimingConfig();
    Logger::println();

    // センサー初期化
    if (!sensorReader.begin()) {
        Logger::println("ERROR: Sensor initialization failed!");
        while (1) {
            delay(100);
        }
    }

    // ステアリングコントローラー初期化
    steeringController.begin();

    // アクチュエーター初期化
    actuator.begin();

    // ESCアーミング待ち
    Logger::println("Waiting 3 seconds for ESC arming...");
    delay(3000);

    Logger::println();
    Logger::println("System ready!");
    Logger::println();
}

// ============================================================================
// Loop関数
// ============================================================================
void loop() {
    static unsigned long lastMeasurement = 0;
    unsigned long currentTime = millis();

#if ENABLE_BLUETOOTH_EMERGENCY
    // Bluetooth経由で入力があれば緊急停止
    if (Serial1.available()) {
        actuator.setSteering(0.0);
        actuator.stop();
        while (1) {
            delay(1000);
        }  // 終了
    }
#endif

    // 指定した間隔で測定・制御（固定周期を維持）
    if (currentTime - lastMeasurement >= MEASUREMENT_INTERVAL) {
        lastMeasurement += MEASUREMENT_INTERVAL;

        // タイミング計測開始
        unsigned long loopStartUs = micros();

        // =========================================================================
        // Phase 1: センサーデータ取得
        // =========================================================================
        unsigned long sensorStartUs = micros();
        sensorReader.readAll();
        unsigned long sensorEndUs = micros();
        unsigned long sensorElapsedUs = sensorEndUs - sensorStartUs;

        const SensorData* sensorData = sensorReader.getAllData();

        // デバッグ: センサーデータ表示
        for (uint8_t i = 0; i < NUM_SENSORS; ++i) {
            Logger::printSensorData(SENSOR_CHANNELS[i], sensorData[i].distance,
                                    sensorData[i].valid);
            if (i < NUM_SENSORS - 1) {
                Logger::print(" | ");
            }
        }

        // =========================================================================
        // Phase 2: 緊急停止チェック（前方障害物検出）
        // =========================================================================
        bool emergency_stop = false;
        if (sensorData[2].valid &&
            sensorData[2].distance < EMERGENCY_FRONT_THRESHOLD) {
            emergency_stop = true;
            Logger::print(" | EMERGENCY!");
        }

        // =========================================================================
        // Phase 3: ギャップ検出（最遠+隣接センサー方式）
        // =========================================================================
        GapResult gap = gapFinder.find(sensorData);

        // デバッグ: ギャップ検出結果表示
        Logger::printGapResult(gap.target_angle, gap.farthest_distance);

        // =========================================================================
        // Phase 4: ステアリング角度計算（PD制御 + 直進モード判定）
        // =========================================================================
        float steering_angle = steeringController.calculate(gap, sensorData);

        // デバッグ: 目標角度とステアリング表示
        Logger::printSteering(steering_angle);

        // =========================================================================
        // Phase 5: アクチュエーター制御
        // =========================================================================
        if (emergency_stop) {
            // 緊急停止：中央ステアリング + 停止
            actuator.setSteering(0.0);
            actuator.stop();
        } else {
            // 通常走行：ステアリング角度とセンサーデータに応じた可変速度
            actuator.setSteering(steering_angle);
            uint16_t variable_speed =
                actuator.calculateSpeed(steering_angle, sensorData);
            actuator.setSpeed(variable_speed);
        }

        // タイミング計測終了・表示
        unsigned long loopEndUs = micros();
        unsigned long loopElapsedUs = loopEndUs - loopStartUs;
        Logger::printLoopTiming(loopElapsedUs, sensorElapsedUs);

        Logger::println("");
    }
}

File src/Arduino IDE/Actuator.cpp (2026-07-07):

#include "Actuator.h"
#include "Logger.h"

Actuator::Actuator() : _currentSpeed(0) {}

void Actuator::begin() {
#if ENABLE_PWM
    // 1. Asignación de Timers e inicialización del Servo de Dirección
    // Esto asegura que use los mismos recursos de hardware que funcionaron en el sweep
    ESP32PWM::allocateTimer(0);
    ESP32PWM::allocateTimer(1);
    
    _steeringServo.setPeriodHertz(50); // Frecuencia estándar para servos (50Hz)
    
    // IMPORTANTE: Enlazamos el pin asignándole su rango de pulso mínimo y máximo (1000us a 2000us)
    // Esto permite que el método map(grados, 0, 180, 1000, 2000) sea totalmente preciso
    _steeringServo.attach(SERVO_PIN, 1000, 2000); 
    
    // Colocamos el servo en la posición central calibrada en grados (ej: 45°) nada más arrancar
    // Convertimos esos grados iniciales a microsegundos para mantener la coherencia del driver
    int pulse_center_us = map(SERVO_CENTER_DEG, 0, 180, 1000, 2000);
    _steeringServo.writeMicroseconds(pulse_center_us);

    // 2. Inicialización del Puente H del Motor (TB6612FNG)
    pinMode(MOTOR_IN1_PIN, OUTPUT);
    pinMode(MOTOR_IN2_PIN, OUTPUT);
    
    // Configuramos el motor en el Canal 4 (PWM a 20kHz, 8 bits) para no interferir con el servo
    ledcSetup(4, 20000, 8); 
    ledcAttachPin(MOTOR_PWMA_PIN, 4); 

    // Estado inicial seguro: Coche completamente detenido
    stop();

    Logger::println("Actuadores Inicializados con Calibración en Grados:");
    Logger::print("  Servo Pin: "); Logger::print(SERVO_PIN);
    Logger::print(" | Centro: "); Logger::print(SERVO_CENTER_DEG); Logger::println("°");
    Logger::print("  Motor Pines: IN1="); Logger::print(MOTOR_IN1_PIN);
    Logger::print(", IN2="); Logger::print(MOTOR_IN2_PIN);
    Logger::print(", PWM(Ch4)="); Logger::println(MOTOR_PWMA_PIN);
#else
    Logger::println("DEBUG MODE: Actuadores desactivados (Sin salidas físicas PWM)");
#endif
}

void Actuator::setSteering(float angle_degrees) {
    // 1. Traducir el ángulo teórico del software (Pure Pursuit) a grados reales del servo.
    // El software calcula: Negativo = Izquierda, Positivo = Derecha.
    // Tu servo físico hace: Grados altos (90) = Izquierda, Grados bajos (0) = Derecha.
    int target_servo_deg = map((int)(angle_degrees * 10),
                               (int)(-MAX_STEERING_ANGLE * 10),
                               (int)(MAX_STEERING_ANGLE * 10),
                               SERVO_LEFT_MAX_DEG * 10,   // Izquierda teórica -> Grados altos (ej: 900)
                               SERVO_RIGHT_MAX_DEG * 10); // Derecha teórica   -> Grados bajos (ej: 0)

    // Dividimos entre 10 para regresar a la escala normal de grados enteros
    int final_deg = target_servo_deg / 10;

    // 2. Filtro de seguridad (Clamp) para que el servo nunca intente ir más allá de tus límites configurados
    // Aseguramos el rango numérico estándar entre el mínimo y máximo en grados
    int min_allowed = (SERVO_RIGHT_MAX_DEG < SERVO_LEFT_MAX_DEG) ? SERVO_RIGHT_MAX_DEG : SERVO_LEFT_MAX_DEG;
    int max_allowed = (SERVO_RIGHT_MAX_DEG > SERVO_LEFT_MAX_DEG) ? SERVO_RIGHT_MAX_DEG : SERVO_LEFT_MAX_DEG;
    
    if (final_deg < min_allowed) final_deg = min_allowed;
    if (final_deg > max_allowed) final_deg = max_allowed;

#if ENABLE_PWM
    // 3. Convertir los grados finales a microsegundos precisos (0° -> 1000us, 180° -> 2000us)
    // Esto replica exactamente lo que hace el método .write() por dentro, garantizando compatibilidad
    int pulse_us = map(final_deg, 0, 180, 1000, 2000);
    
    _steeringServo.writeMicroseconds(pulse_us);
#endif

    Logger::printActuator("Servo Grados Reales", final_deg);
}

void Actuator::setSpeed(uint8_t speed_pwm) {
    _currentSpeed = speed_pwm;
#if ENABLE_PWM
    if (_currentSpeed == 0) {
        stop();
        return;
    }
    digitalWrite(MOTOR_IN1_PIN, HIGH);
    digitalWrite(MOTOR_IN2_PIN, LOW);
    ledcWrite(4, _currentSpeed); // Canal 4
#endif
}

void Actuator::stop() {
    _currentSpeed = 0;
#if ENABLE_PWM
    digitalWrite(MOTOR_IN1_PIN, LOW);
    digitalWrite(MOTOR_IN2_PIN, LOW);
    ledcWrite(4, 0); // Canal 4
#endif
}

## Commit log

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2025-12-10 refactor: Extract magic numbers to class constants in Vehicle
    - マジックナンバー 0.001, 0.05, 0.8, 0.1 を定数化
    - STEERING_THRESHOLD_STRAIGHT: ほぼ直進とみなす閾値 (0.001 rad)
    - STEERING_THRESHOLD_DAMPING: 強い減衰を適用する閾値 (0.05)
    - ANGULAR_DAMPING_STRONG: 強い角速度減衰係数 (0.8)
    - ANGULAR_DAMPING_NORMAL: 通常の角速度減衰係数 (0.1)
    フェーズ1完了: 可読性と保守性が向上
2025-12-10 Refactor: Eliminate vehicle size duplication
    車両サイズの重複定義を解消しました。
    ## 変更内容
    - Renderer.draw_vehicle()のシグネチャを変更: 車両オブジェクトを受け取るように
    - renderer.pyからハードコードされた車両サイズ(0.4m, 0.2m)を削除
    - 車両サイズはvehicle.pyの1箇所のみで定義される
    - minicar_env.pyのdraw_vehicle()呼び出しを簡素化
    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
2025-12-10 refactor: Split apply_control into smaller methods
    apply_controlメソッドを以下のサブメソッドに分割：
    - _normalize_control: 制御入力の正規化
    - _compute_wheel_positions: ホイール位置の計算
    - _apply_tire_friction: タイヤの横滑り抑制
    - _apply_drive_force: 駆動力の適用
    - _apply_angular_damping: 角速度の減衰
    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
2025-12-10 refactor: Unify lateral velocity suppression methods
    _kill_lateral_velocity_at_centerと_kill_lateral_velocityを統合：
    - 新しい_kill_lateral_velocityは world_point をオプショナルに
    - world_point=None の場合は重心に適用（トルクなし）
    - world_point指定時は指定位置に適用
    改善効果：
    - コード重複を約30行削減（85%の重複を解消）
    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
2025-12-10 feat: update vehicle dimensions to match real TT-02 (Phase 1)
    - Update width: 0.2m → 0.188m (real: 188mm)
    - Update length: 0.4m → 0.479m (real: 479mm)
    - Update wheelbase: 0.28m → 0.257m (real: 257mm)
    Effects:
    - Turning radius: 0.51m → 0.47m (8% tighter)
    - Diagonal radius: 0.224m → 0.257m (matches real vehicle)
    - Minimized sim-to-real gap
2025-12-10 feat: adjust vehicle mass to 1.4kg including battery (Phase 2)
    車両質量を実機に合わせて1.0kgから1.4kgに調整しました。
    変更内容:
    - 質量: 1.0kg → 1.4kg (車体1.2kg + バッテリー0.2kg)
    期待される効果:
    - 加速度: 20 m/s² → 14.3 m/s² (約30%減少)
    - 制動距離が約40%増加
    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
2025-12-20 fixed sensor para. it worked
    [Config.h, Logger.h, five_sensor_reader.ino]
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2025-12-24 small fix. it worked
    [Config.h]
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2026-01-06 μsに統一. L1Xに修正済
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2026-01-07 test for new ESC value. its not work
    [Actuator.cpp, Config.h]
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2026-01-09 fix range of servo pulse. its not worked
    [Config.h]
2026-01-09 fixing NO GAP issue
    [Config.h]
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2026-01-22 Ld=正面センサから一定距離を減算する件のdocs修正
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2026-02-06 fix: Bluetooth(HC-06)関連コードを全削除
    HC-06モジュールをシステムから完全に取り外したため、
    関連する実装・設定・ドキュメントを全て削除。
    削除内容:
    - Config.h: ENABLE_BLUETOOTH_EMERGENCY, BLUETOOTH_BAUD
    - Logger.h: Serial1.begin() 初期化
    - seven.ino: Bluetooth緊急停止チェック処理
    - CLAUDE.md, README.md: Bluetooth関連の記述
    [Config.h, Logger.h]
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2026-02-15 docs: センサー配置角度を±60°に修正、SPEED_USを1680に更新
2026-05-08 docs: translate all comments and documentation to English (#25)
    Translate Japanese comments and documentation to English across the
    Arduino sources (seven/) and the project docs (README.md, CLAUDE.md).
    Runtime behavior is unchanged: serial output strings and code
    identifiers are preserved verbatim.
    Update CLAUDE.md "Language" section to reflect the new English-first
    policy for code, comments, and documentation. Conversational replies
    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
2026-05-15 Expand README with engineering materials information
    Added detailed descriptions of repository contents and purpose.
2026-05-23 Enhance README with chassis optimization details
    Added section on chassis optimization to the design process.
2026-05-23 Add design process documentation for chassis optimization
    Documented the design process for chassis optimization, detailing modifications made to accommodate available fasteners and structural improvements.
2026-05-23 Optimize chassis design for fastener availability
    Redesigned chassis to adapt fasteners for local availability while maintaining structural integrity. Implemented a hybrid design using M4 bolts for the main structure and M3 for critical components.
2026-05-23 Revise chassis optimization section for clarity
    Clarified the impact of hole diameter changes on structural integrity and detailed the hybrid design approach for fasteners. Added information about the modification to the steering mechanism for imp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
2026-06-29 Revise chassis design for zcar with local fasteners
    The modifications include redesigning the chassis model in Fusion 360 for better compatibility with local fasteners, addressing structural integrity issues, and enhancing the steering mechanism for improved performance.
2026-06-29 Enhance README with design changes and new image
    Updated the README with a new image and modifications to the steering mechanism and drive axle.
2026-06-29 Document control board development and integration issues
    Added a section detailing the development of the control board, including challenges with sensor integration and the final solution using a Raspberry Pi.
2026-07-09 Fix typo in README section title for sensors
2026-07-09 Update README with VL53L0X sensor information
    Added details about the VL53L0X distance sensor, including its advantages and an image.
2026-07-09 Update header level for VL53L0X section
    Changed header level for VL53L0X Distance Sensor section.
2026-07-09 Document webcam integration and modifications
    Added a section about the modified 1080p FHD webcam, detailing its advantages and dimensions compared to the original housing.
2026-07-11 Refine advantages for sensors and webcam
    Updated the advantages section for VL53L0X, MPU-6050, and modified webcam to improve clarity and formatting.
2026-07-11 Update README with Raspberry Pi and ESP32-S2 details
    Added details about the Raspberry Pi 3 B+ and ESP32-S2 Mini specifications and processing capabilities.
2026-07-13 Filtro 1D Kalman y resolverpista agregados
    [Actuator.py, Config.py, Kalman.py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]
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2026-07-15 Translate README.md to Spanish
    Translated README content from English to Spanish, including team introduction, project overview, and sections on mobility, power architecture, and components.
2026-07-15 Enhance README with ESP32-S2 Mini integration details
    Added details about using ESP32-S2 Mini for sensor control and Wi-Fi connectivity for real-time data transmission.
2026-07-15 Add ESP32-S2 Mini information to README
    Updated the README to include ESP32-S2 Mini details.
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2026-07-16 Revise battery details and power distribution explanation
    Updated battery specifications and added rationale for selection. Included details on power distribution and noise isolation strategies.
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2026-08-06 barra de dirección
    [barra direccion.stl]
2026-08-06 Caja para la batería
    [caja bateria.stl]
2026-08-06 Rename Batería.stl to Caja de Batería.stl
    [Caja de Batería.stl]
2026-08-06 Rename caja bateria.stl to Tapa para la caja de la batería.stl
    [Tapa para la caja de la batería.stl]
2026-08-06 Rename front-tire.stl to Cauchos delanteros.stl
    [Cauchos delanteros.stl]
2026-08-06 Pin para sostener los sensores en su base.
    [pin de sensores.stl]
2026-08-06 Rename Soporte suspension traserea.stl to Soporte suspension trasera.stl
    [Soporte suspension trasera.stl]
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2026-08-08 Fix formatting in Config.py
    [Config.py]
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2026-09-09 Calibración del PID, diseño de proceso agregado y README modificado
    [Caja de Batería.stl, Caucho.stl, Cauchos delanteros.stl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]
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
